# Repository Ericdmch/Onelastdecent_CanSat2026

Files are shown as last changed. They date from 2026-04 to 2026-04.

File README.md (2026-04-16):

# CanSat 2026

A student CanSat project for the 2026 competition. The system consists of a CanSat satellite unit that collects and transmits environmental and navigation telemetry, a ground station receiver that captures the radio packets, and a Python dashboard for real-time display and data logging.

---

## Repository Structure

```
Onelastdecent_CanSat2026/
├── Hardware/
│   ├── CanSat 2026.step          # CanSat mechanical design
│   └── Ground Station.step       # Ground station enclosure design
└── Software/
    ├── CanSat_Main_Transmitter/  # CanSat onboard firmware (Pico 2 W)
    └── CanSat_Main_Reciever/     # Ground station firmware (Pico 2) + dashboard
        └── dashboard/            # Python ground station dashboard
```

---

## System Overview

### CanSat (Transmitter)

**Hardware**
| Component | Part | Interface |
|---|---|---|
| Microcontroller | Raspberry Pi Pico 2 W (RP2350) | — |
| Environmental sensor | BME680 | I2C0 — SDA GP4, SCL GP5 |
| Radio | E220-900T30D (LoRa 915 MHz, 30 dBm) | UART0 — TX GP0, RX GP1, M0 GP2, M1 GP3, AUX GP6 |
| Flight controller | MicoAir743V2 (ArduPilot) — GPS + IMU | UART1 — TX GP8, RX GP9 |
| Status LED | WS2812B NeoPixel | PIO — GP7 |

The CanSat firmware runs at 1 Hz. Each loop it reads the BME680, polls the flight controller for GPS position and attitude over MAVLink, builds a CSV telemetry packet, and transmits it via the E220 radio. Sensor values are also logged to the flight controller's DataFlash via `NAMED_VALUE_FLOAT` MAVLink messages.

**NeoPixel status codes**

| Colour | Meaning |
|---|---|
| Green | All sensors valid, radio OK |
| Yellow | BME680 invalid, radio OK |
| Orange | Radio transmit timeout |
| Red | BME680 not found at boot |

---

### Ground Station (Receiver)

**Hardware**
| Component | Part | Interface |
|---|---|---|
| Microcontroller | Raspberry Pi Pico 2 (RP2350) | — |
| Radio | E220-900T30D (LoRa 915 MHz, 30 dBm) | UART0 — TX GP0, RX GP1, M0 GP2, M1 GP3, AUX GP6 |
| GPS | HGLRC M100-5883 | UART1 — TX GP4, RX GP5 |
| Status LED | WS2812B NeoPixel | PIO — GP7 |
| Onboard LED | GP25 | GPIO |

The receiver firmware forwards received `$CANSAT` packets verbatim to USB serial. It also parses NMEA GGA sentences from the ground station GPS and emits `$GSPOS` lines to USB so the dashboard can display the ground station's own position and calculate distance/bearing to the CanSat.

**NeoPixel status codes**

| Colour | Meaning |
|---|---|
| Green flash | Packet received |
| Red flash | No packet in the last 2 s |
| Solid orange | E220 configuration in progress |

---

## Telemetry Packet Format

All packets are newline-terminated ASCII sent over USB serial at any baud rate.

**CanSat telemetry**
```
$CANSAT,<ms>,<temp>,<press>,<hum>,<gas>,<lat_e7>,<lon_e7>,<alt_mm>,<roll>,<pitch>,<yaw>,<fc_bytes>,<stx_v1>,<stx_v2>
```

| Field | Unit | Notes |
|---|---|---|
| `ms` | ms | Time since boot |
| `temp` | °C | BME680 temperature (PCB offset applied) |
| `press` | hPa | Barometric pressure |
| `hum` | % | Relative humidity |
| `gas` | Ω | Gas resistance |
| `lat_e7` / `lon_e7` | deg × 10⁷ | GPS position from ArduPilot FC |
| `alt_mm` | mm | GPS altitude |
| `roll` / `pitch` / `yaw` | deg | Attitude from ArduPilot FC |
| `fc_bytes` / `stx_v1` / `stx_v2` | — | FC UART debug counters |

**Ground station GPS**
```
$GSPOS,<lat_e7>,<lon_e7>,<alt_mm>,<hdop_100>,<fix>
```

**Radio frequency broadcast** (sent by CanSat every ~10 s)
```
$FREQ,<freq_mhz>,<channel>
```

---

## Radio Configuration

Both E220 modules are configured at boot to:

| Parameter | Value |
|---|---|
| Frequency | 915.125 MHz (channel 65) |
| Air data rate | 2.4 kbps |
| UART baud | 9600 |
| TX power | 30 dBm |
| Sub-packet size | 200 B |
| Mode | Transparent |

---

## Ground Station Dashboard

A Python/Tkinter application providing real-time telemetry display, live graphs, a GPS map view, and CSV data recording.

### Setup

```bash
cd Software/CanSat_Main_Reciever/dashboard
pip install -r requirements.txt
python3 ground_station.py
```

**Dependencies:** `pyserial`, `matplotlib`, `tkintermapview` (optional — required for tile map view)

### Features

- Connect to any serial port at 9600 or 115200 baud
- Live telemetry panel: environmental, navigation, and attitude data
- Six real-time graphs: temperature, pressure, humidity, altitude, orientation, gas resistance
- GPS map tab with tile map (online) and simple offline scatter plot
- Ground station GPS overlay showing position, distance, and bearing to CanSat
- Radio frequency badge updated automatically from `$FREQ` packets
- CSV recording and export
- Signal loss overlay when no packets are received for > 5 s

---

## Firmware Build Instructions

Both firmware projects use the [Raspberry Pi Pico SDK](https://github.com/raspberrypi/pico-sdk) and are configured for VS Code with the Pico extension.

**Prerequisites:** CMake ≥ 3.13, ARM GCC toolchain, Pico SDK 2.2.0

```bash
cd Software/CanSat_Main_Transmitter   # or CanSat_Main_Reciever
mkdir build && cd build
cmake ..
make -j4
```

Flash the resulting `.uf2` file by holding BOOTSEL on the Pico while connecting via USB, then copying the file to the mounted drive.

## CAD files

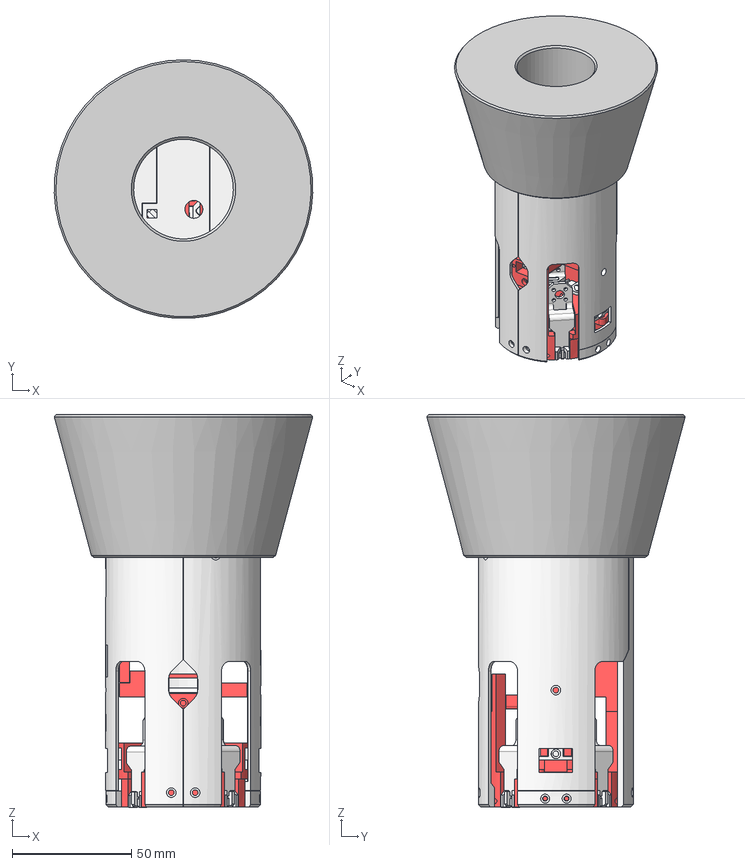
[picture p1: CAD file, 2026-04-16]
Hardware/CanSat 2026.step
108.3 x 108.3 x 164.6 mm

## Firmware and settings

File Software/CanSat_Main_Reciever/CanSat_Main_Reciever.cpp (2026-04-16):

//
// CanSat 2026 — Ground Station Receiver Firmware
// Controller : Raspberry Pi Pico 2 (RP2350 Cortex-M33)
// Radio      : E220-900T30D via UART0 (TX=GP0, RX=GP1, M0=GP2, M1=GP3, AUX=GP6)
// Output     : USB serial — open at any baud rate in a serial monitor
//
// Received packets are forwarded verbatim to USB:
//   $CANSAT,<ms>,<temp>,<press>,<hum>,<gas>,<lat_e7>,<lon_e7>,<alt_mm>,<roll>,<pitch>,<yaw>
//

#include "pico/stdlib.h"
#include "hardware/uart.h"
#include "hardware/gpio.h"
#include "hardware/watchdog.h"
#include "hardware/pio.h"
#include "hardware/clocks.h"
#include "ws2812.pio.h"
#include <cstdint>
#include <cstdio>
#include <cstdlib>
#include <cstring>

static constexpr uint LED_PIN  = 25;

// ── NeoPixel (WS2812) ─────────────────────────────────────────────────────
static constexpr uint NEO_PIN  = 7;
static PIO  neo_pio = pio0;
static uint neo_sm  = 0;

static void neo_init() {
    uint offset = pio_add_program(neo_pio, &ws2812_program);
    ws2812_program_init(neo_pio, neo_sm, offset, NEO_PIN, 800000.f);
}

// Send 24-bit GRB color (WS2812 expects G-R-B order in the upper 24 bits)
static void neo_set(uint8_t r, uint8_t g, uint8_t b) {
    uint32_t grb = ((uint32_t)g << 24) | ((uint32_t)r << 16) | ((uint32_t)b << 8);
    pio_sm_put_blocking(neo_pio, neo_sm, grb);
}

// Brief color flash then off
static void neo_flash(uint8_t r, uint8_t g, uint8_t b, uint32_t ms) {
    neo_set(r, g, b);
    sleep_ms(ms);
    neo_set(0, 0, 0);
}

// ── E220 pin assignments ───────────────────────────────────────────────────
#define E220_UART      uart0
static constexpr uint E220_TX_PIN  = 0;
static constexpr uint E220_RX_PIN  = 1;
static constexpr uint E220_M0_PIN  = 2;
static constexpr uint E220_M1_PIN  = 3;
static constexpr uint E220_AUX_PIN = 6;
static constexpr uint E220_BAUD    = 9600;

// ── Watchdog ───────────────────────────────────────────────────────────────
static constexpr uint32_t WATCHDOG_MS = 8000;

// ── Packet buffer ─────────────────────────────────────────────────────────
static constexpr size_t BUF_SIZE = 256;

// ── Ground-Station GPS (UART1, HGLRC M100-5883) ───────────────────────────
// Wiring: GP4 → GPS RX (optional, config only),  GP5 ← GPS TX (NMEA out)
#define GPS_UART     uart1
static constexpr uint GPS_TX_PIN = 4;
static constexpr uint GPS_RX_PIN = 5;
static constexpr uint GPS_BAUD   = 9600;
static constexpr size_t GPS_LINE_SIZE = 128;

static struct {
    int32_t  lat_e7;
    int32_t  lon_e7;
    int32_t  alt_mm;
    uint16_t hdop_100;
    uint8_t  fix;      // 0 = no fix
} gs_gps = {};

static void gps_init() {
    uart_init(GPS_UART, GPS_BAUD);
    gpio_set_function(GPS_TX_PIN, GPIO_FUNC_UART);
    gpio_set_function(GPS_RX_PIN, GPIO_FUNC_UART);
    uart_set_format(GPS_UART, 8, 1, UART_PARITY_NONE);
    uart_set_fifo_enabled(GPS_UART, true);
    printf("[GPS] UART1 init: TX=GP%d RX=GP%d @%d baud\n",
           GPS_TX_PIN, GPS_RX_PIN, GPS_BAUD);
}

// Convert NMEA "DDMM.MMMMM" + hemisphere to integer degrees * 1e7
static int32_t nmea_to_e7(const char* s, char hemi) {
    if (!s || s[0] == '\0') return 0;
    int dot = 0;
    while (s[dot] && s[dot] != '.') dot++;
    if (dot < 2) return 0;
    int deg_chars = dot - 2;
    int32_t deg = 0;
    for (int i = 0; i < deg_chars; i++) {
        if (s[i] < '0' || s[i] > '9') return 0;
        deg = deg * 10 + (s[i] - '0');
    }
    double min = atof(s + deg_chars);
    double dd  = (double)deg + min / 60.0;
    if (hemi == 'S' || hemi == 'W') dd = -dd;
    return (int32_t)(dd * 1e7 + (dd >= 0.0 ? 0.5 : -0.5));
}

// Split a NMEA sentence in-place on ',' and '*'. Returns field count.
static int nmea_split(char* s, char* f[], int max) {
    int n = 0;
    f[n++] = s;
    while (*s && n < max) {
        if (*s == ',' || *s == '*') { *s = '\0'; f[n++] = s + 1; }
        s++;
    }
    return n;
}

// Parse any $GxGGA sentence and emit $GSPOS on USB
static void gps_parse_line(char* line) {
    // Accept $GPGGA, $GNGGA, $GLGGA, etc.
    if (line[0] != '$' || line[1] != 'G' ||
        line[3] != 'G' || line[4] != 'G' || line[5] != 'A' || line[6] != ',')
        return;

    char* f[20];
    int n = nmea_split(line, f, 20);
    if (n < 10) return;

    // f indices: 0=id 1=time 2=lat 3=N/S 4=lon 5=E/W 6=fix 7=sats 8=hdop 9=alt
    int fix = atoi(f[6]);
    if (fix == 0) { gs_gps.fix = 0; return; }

    gs_gps.lat_e7   = nmea_to_e7(f[2], f[3][0]);
    gs_gps.lon_e7   = nmea_to_e7(f[4], f[5][0]);
    gs_gps.alt_mm   = (int32_t)(atof(f[9]) * 1000.0 + 0.5);
    gs_gps.hdop_100 = (uint16_t)(atof(f[8]) * 100.0 + 0.5);
    gs_gps.fix      = (uint8_t)fix;

    printf("$GSPOS,%ld,%ld,%ld,%u,%u\n",
           (long)gs_gps.lat_e7, (long)gs_gps.lon_e7,
           (long)gs_gps.alt_mm, gs_gps.hdop_100, gs_gps.fix);
}

static char gps_buf[GPS_LINE_SIZE];
static int  gps_pos = 0;

static void gps_handle_char(char c) {
    if (c == '\n') {
        gps_buf[gps_pos] = '\0';
        if (gps_pos > 0 && gps_buf[0] == '$')
            gps_parse_line(gps_buf);
        gps_pos = 0;
    } else if (c != '\r') {
        if (gps_pos < (int)sizeof(gps_buf) - 1)
            gps_buf[gps_pos++] = c;
        else
            gps_pos = 0;  // overflow — discard
    }
}

// ── E220 helpers ──────────────────────────────────────────────────────────

static void e220_flush_rx_verbose() {
    while (uart_is_readable(E220_UART)) {
        uint8_t c = uart_getc(E220_UART);
        printf("  (flushed byte: 0x%02X)\n", c);
    }
}

static void e220_flush_rx() {
    int n = 0;
    while (uart_is_readable(E220_UART)) { uart_getc(E220_UART); n++; }
    if (n) printf("  (flushed %d bytes)\n", n);
}

static int e220_read_resp(uint8_t* buf, int max_len, uint32_t first_byte_us) {
    int len = 0;
    uint32_t timeout = first_byte_us;
    while (len < max_len && uart_is_readable_within_us(E220_UART, timeout)) {
        buf[len++] = uart_getc(E220_UART);
        timeout = 10000; // subsequent bytes: 10ms
    }
    return len;
}

static void e220_print_hex(const char* label, const uint8_t* buf, int len) {
    printf("%s", label);
    for (int i = 0; i < len; i++) printf("%02X ", buf[i]);
    printf("(%d bytes)\n", len);
}

// ── Probe: try BOTH binary and AT protocol ──────────────────────────────

enum ProbeResult { PROBE_NONE, PROBE_BINARY, PROBE_AT };

static ProbeResult e220_probe() {
    uint8_t resp[20];
    int rlen;

    // --- Try binary: C1 00 08 (reference library format) ---
    e220_flush_rx();
    const uint8_t bin_cmd[] = {0xC1, 0x00, 0x08};
    uart_write_blocking(E220_UART, bin_cmd, 3);
    sleep_ms(100);
    rlen = e220_read_resp(resp, sizeof(resp), 100000);
    if (rlen > 0) {
        e220_print_hex("  bin rx: ", resp, rlen);
        if (rlen >= 3 && resp[0] == 0xC1) return PROBE_BINARY;
    }

    // --- Try AT text: AT+ADDR?\r\n ---
    e220_flush_rx();
    const char* at_cmd = "AT+ADDR?\r\n";
    uart_write_blocking(E220_UART, (const uint8_t*)at_cmd, strlen(at_cmd));
    sleep_ms(200);
    rlen = e220_read_resp(resp, sizeof(resp), 100000);
    if (rlen > 0) {
        resp[rlen < 19 ? rlen : 19] = '\0';
        printf("  at rx: \"%s\" (%d bytes)\n", (char*)resp, rlen);
        if (strstr((char*)resp, "OK") || strstr((char*)resp, "AT") || rlen >= 2)
            return PROBE_AT;
    }

    return PROBE_NONE;
}

// ── Config write (binary protocol) ──────────────────────────────────────

static bool e220_write_config_binary() {
    // C0 = permanent save (per reference library; C2 = temporary)
    const uint8_t config[] = {
        0xC0,   // permanent write
        0x00,   // start register
        0x08,   // 8 registers (no NETID in this variant)
        0x00,   // ADDH  = 0
        0x00,   // ADDL  = 0
        0x62,   // SPED: UART 9600, 8N1, air 2.4 kbps
        0x00,   // OPTION: sub-pkt 200B, RSSI off, 30 dBm
        0x41,   // CHAN: channel 65 → 915.125 MHz
        0x00,   // TRANS_MODE: transparent, no relay/LBT/WOR
        0x00,   // CRYPT_H
        0x00,   // CRYPT_L
    };

    e220_flush_rx();
    uart_write_blocking(E220_UART, config, sizeof(config));
    sleep_ms(200);

    uint8_t resp[16];
    int rlen = e220_read_resp(resp, sizeof(resp), 100000);
    if (rlen >= 3 && resp[0] == 0xC1) {
        e220_print_hex("[E220] Write OK (bin): ", resp, rlen);
        return true;
    }
    if (rlen > 0) e220_print_hex("[E220] Write resp: ", resp, rlen);
    return false;
}

// ── Config write (AT protocol) ──────────────────────────────────────────

static bool e220_at_cmd(const char* cmd) {
    e220_flush_rx();
    uart_write_blocking(E220_UART, (const uint8_t*)cmd, strlen(cmd));
    sleep_ms(200);

    char resp[32];
    int rlen = 0;
    while (rlen < (int)sizeof(resp) - 1 && uart_is_readable_within_us(E220_UART, 50000)) {
        uint8_t c = uart_getc(E220_UART);
        if (c >= 0x20 && c < 0x7f) resp[rlen++] = (char)c;
    }
    resp[rlen] = '\0';

    if (rlen > 0) printf("  [%s] -> \"%s\"\n", cmd, resp);
    return strstr(resp, "OK") != nullptr;
}

static void e220_write_config_at() {
    const char* cmds[] = {
        "AT+ADDR=0\r\n",
        "AT+CHANNEL=65\r\n",
        "AT+RATE=2\r\n",
        "AT+TRANS=0\r\n",
        "AT+POWER=0\r\n",
        "AT+UART=3,0\r\n",
        "AT+PACKET=0\r\n",
    };
    for (int i = 0; i < 7; i++) {
        if (!e220_at_cmd(cmds[i]))
            printf("  WARN: %s no OK\n", cmds[i]);
    }
}

// ── E220 configure ──────────────────────────────────────────────────────

static void e220_configure() {
    // --- GPIO: start with M0=HIGH, M1=HIGH (config mode from boot) ---
    gpio_init(E220_M0_PIN);  gpio_set_dir(E220_M0_PIN, GPIO_OUT);  gpio_put(E220_M0_PIN, 1);
    gpio_init(E220_M1_PIN);  gpio_set_dir(E220_M1_PIN, GPIO_OUT);  gpio_put(E220_M1_PIN, 1);
    gpio_init(E220_AUX_PIN); gpio_set_dir(E220_AUX_PIN, GPIO_IN);
    gpio_pull_up(E220_AUX_PIN);

    // --- UART ---
    uint actual_baud = uart_init(E220_UART, E220_BAUD);
    gpio_set_function(E220_TX_PIN, GPIO_FUNC_UART);
    gpio_set_function(E220_RX_PIN, GPIO_FUNC_UART);
    uart_set_format(E220_UART, 8, 1, UART_PARITY_NONE);
    uart_set_fifo_enabled(E220_UART, true);

    printf("[E220] UART baud=%u actual=%u\n", E220_BAUD, actual_baud);
    printf("[E220] Pins: TX=GP%d RX=GP%d M0=GP%d M1=GP%d AUX=GP%d\n",
           E220_TX_PIN, E220_RX_PIN, E220_M0_PIN, E220_M1_PIN, E220_AUX_PIN);

    // --- Line-level check ---
    gpio_set_function(E220_RX_PIN, GPIO_FUNC_SIO);
    gpio_set_dir(E220_RX_PIN, GPIO_IN);
    gpio_disable_pulls(E220_RX_PIN);
    sleep_ms(5);
    bool rx_level = gpio_get(E220_RX_PIN);
    printf("[E220] GP1 (RX) no-pull=%d %s\n", rx_level,
           rx_level ? "(E220 TXD connected)" : "*** NOT CONNECTED ***");
    gpio_set_function(E220_RX_PIN, GPIO_FUNC_UART);

    // --- Wait for AUX HIGH ---
    printf("[E220] Waiting for AUX HIGH (config mode)...\n");
    for (int i = 0; i < 300; i++) {
        if (gpio_get(E220_AUX_PIN)) break;
        if (i % 50 == 0) printf("  AUX=%d @%dms\n", gpio_get(E220_AUX_PIN), i * 10);
        sleep_ms(10);
    }
    sleep_ms(200);

    // Print the stale byte if there is one
    e220_flush_rx_verbose();

    printf("[E220] M0=%d M1=%d AUX=%d — probing...\n",
           gpio_get(E220_M0_PIN), gpio_get(E220_M1_PIN), gpio_get(E220_AUX_PIN));

    // --- Probe at multiple baud rates and all M0/M1 mode combos ---
    const uint32_t bauds[] = {9600, 115200, 57600, 19200, 38400, 4800, 2400, 1200};
    const int num_bauds = sizeof(bauds) / sizeof(bauds[0]);

    ProbeResult result = PROBE_NONE;

    // First: try 9600 with M0=1 M1=1 (standard config mode), 5 quick probes
    printf("[E220] === 9600 baud, M0=1 M1=1 (5 probes) ===\n");
    for (int i = 0; i < 5 && result == PROBE_NONE; i++) {
        printf("  [probe %d] ", i + 1);
        result = e220_probe();
        if (result == PROBE_NONE) { printf("  no response\n"); sleep_ms(300); }
    }

    // Second: try all other baud rates with M0=1 M1=1
    if (result == PROBE_NONE) {
        for (int b = 1; b < num_bauds && result == PROBE_NONE; b++) {
            uart_set_baudrate(E220_UART, bauds[b]);
            printf("[E220] === %lu baud, M0=1 M1=1 ===\n", (unsigned long)bauds[b]);
            e220_flush_rx_verbose();
            for (int i = 0; i < 3 && result == PROBE_NONE; i++) {
                printf("  [probe %d] ", i + 1);
                result = e220_probe();
                if (result == PROBE_NONE) { printf("  no response\n"); sleep_ms(200); }
            }
        }
        // Restore 9600
        uart_set_baudrate(E220_UART, 9600);
    }

    // Third: try other M0/M1 combos at 9600
    if (result == PROBE_NONE) {
        // M0=0 M1=1
        printf("[E220] === 9600 baud, M0=0 M1=1 ===\n");
        gpio_put(E220_M0_PIN, 0); gpio_put(E220_M1_PIN, 1);
        sleep_ms(500);
        for (int i = 0; i < 3 && result == PROBE_NONE; i++) {
            printf("  [probe %d] ", i + 1);
            result = e220_probe();
            if (result == PROBE_NONE) { printf("  no response\n"); sleep_ms(200); }
        }

        // M0=1 M1=0
        printf("[E220] === 9600 baud, M0=1 M1=0 ===\n");
        gpio_put(E220_M0_PIN, 1); gpio_put(E220_M1_PIN, 0);
        sleep_ms(500);
        for (int i = 0; i < 3 && result == PROBE_NONE; i++) {
            printf("  [probe %d] ", i + 1);
            result = e220_probe();
            if (result == PROBE_NONE) { printf("  no response\n"); sleep_ms(200); }
        }

        // Restore config mode
        gpio_put(E220_M0_PIN, 1); gpio_put(E220_M1_PIN, 1);
        sleep_ms(500);
    }

    if (result == PROBE_NONE) {
        printf("\n[E220] Exhausted all baud rates and mode combos. No response.\n");
        printf("  The module is connected (TXD drives GP1 HIGH, AUX HIGH)\n");
        printf("  but does not respond to any command.\n");
        printf("[E220] Continuing without config — using factory defaults.\n");
    }

    // --- Write configuration using whichever protocol worked ---
    if (result == PROBE_BINARY) {
        printf("[E220] Using binary protocol\n");
        if (!e220_write_config_binary())
            printf("[E220] WARN: binary write failed\n");
    } else if (result == PROBE_AT) {
        printf("[E220] Using AT protocol\n");
        e220_write_config_at();
    }
    // result == PROBE_NONE: skip config, use factory defaults

    // --- Return to normal mode ---
    gpio_put(E220_M0_PIN, 0);
    gpio_put(E220_M1_PIN, 0);
    sleep_ms(500);
    for (int i = 0; i < 100; i++) {
        if (gpio_get(E220_AUX_PIN)) break;
        sleep_ms(10);
    }
    printf("[E220] Normal mode. AUX=%d — Ready\n", gpio_get(E220_AUX_PIN));
}

int main() {
    stdio_init_all();
    sleep_ms(3000);  // wait for serial monitor to connect

    gpio_init(LED_PIN);
    gpio_set_dir(LED_PIN, GPIO_OUT);
    neo_init();

    if (watchdog_caused_reboot()) {
        printf("[BOOT] Watchdog reboot\n");
    }

    // Configure E220 — solid orange while busy
    neo_set(255, 80, 0);
    e220_configure();
    neo_set(0, 0, 0);

    // Ground-station GPS
    gps_init();

    watchdog_enable(WATCHDOG_MS, true);
    printf("[OK] Ground station ready — waiting for packets\n");
    gpio_put(LED_PIN, 1); // LED solid = ready

    // ── Receive loop ──────────────────────────────────────────────────────
    char line[BUF_SIZE];
    int  pos = 0;
    uint32_t last_heartbeat_ms = 0;
    uint32_t last_packet_ms    = 0;

    while (true) {
        watchdog_update();

        uint32_t now = to_ms_since_boot(get_absolute_time());
        if (now - last_heartbeat_ms >= 500) {
            printf("[SCAN] Listening for CanSat...\n");
            last_heartbeat_ms = now;
            // Flash red when no packet received in the last 2 s
            if (now - last_packet_ms >= 2000) {
                neo_flash(255, 0, 0, 200);
            }
        }

        // Poll ground-station GPS (UART1)
        while (uart_is_readable(GPS_UART))
            gps_handle_char((char)uart_getc(GPS_UART));

        if (!uart_is_readable(E220_UART)) {
            sleep_us(200);
            continue;
        }

        char c = uart_getc(E220_UART);

        if (c == '\n') {
            line[pos] = '\0';
            if (pos > 0 && line[0] == '$') {
                // Forward complete packet to USB
                printf("%s\n", line);
                last_packet_ms = now;
                // Green flash = packet received; brief LED blink as backup indicator
                neo_flash(0, 255, 0, 15);
                gpio_put(LED_PIN, 0);
                sleep_ms(30);
                gpio_put(LED_PIN, 1);
            }
            pos = 0;
        } else if (c != '\r') {
            if (pos < (int)sizeof(line) - 1) {
                line[pos++] = c;
            } else {
                pos = 0; // line overflow — discard and reset
            }
        }
    }
}

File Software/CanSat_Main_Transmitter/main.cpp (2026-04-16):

//
// CanSat 2026 — Primary Mission Firmware
// Controller : Raspberry Pi Pico 2 W (RP2350 Cortex-M33)
// Sensor     : BME680  via I2C0  (SDA=GP4, SCL=GP5)
// Radio      : E220-900T30D via UART0 (TX=GP0, RX=GP1, M0=GP2, M1=GP3, AUX=GP6)
// FC Link    : MicoAir743V2 (ArduPilot) via UART1 (TX=GP8, RX=GP9)
// NeoPixel   : WS2812B via PIO (DIN=GP7)
//

#include "pico/stdlib.h"
#include "pico/cyw43_arch.h"
#include "hardware/i2c.h"
#include "hardware/watchdog.h"
#include "hardware/clocks.h"

#include "bme680.hpp"
#include "e220.hpp"
#include "fc_link.hpp"
#include "neopixel.hpp"

#include <cstdio>
#include <cstring>

// ── Pin assignments ────────────────────────────────────────────────────────
static constexpr uint I2C0_SDA = 4;
static constexpr uint I2C0_SCL = 5;

// ── Calibration ────────────────────────────────────────────────────────────
static constexpr float TEMP_OFFSET_C = -6.51f; // corrects for PCB self-heating

// ── Radio frequency ────────────────────────────────────────────────────────
static constexpr uint E220_CHANNEL  = 65;
static constexpr float   E220_FREQ_MHZ = 850.125f + E220_CHANNEL; // 915.125 MHz

// ── Timing ─────────────────────────────────────────────────────────────────
static constexpr uint32_t LOOP_PERIOD_MS  = 1000; // 1 Hz telemetry
static constexpr uint32_t WATCHDOG_MS     = 2000; // reboot if loop hangs

// ── Globals ────────────────────────────────────────────────────────────────
static BME680  bme(i2c0);
static E220    radio;
static FCLink  fc;

// ── Helpers ────────────────────────────────────────────────────────────────
static void led_blink(uint n) {
    for (uint i = 0; i < n; i++) {
        cyw43_arch_gpio_put(CYW43_WL_GPIO_LED_PIN, 1); sleep_ms(80);
        cyw43_arch_gpio_put(CYW43_WL_GPIO_LED_PIN, 0); sleep_ms(80);
    }
}

// Build CSV telemetry packet into buf; returns number of chars written
// Format: $CANSAT,<ms>,<temp>,<press>,<hum>,<gas>,<lat_e7>,<lon_e7>,<alt_mm>,<roll_deg>,<pitch_deg>,<yaw_deg>\r\n
static int build_packet(char* buf, size_t bufsz,
                        uint32_t timestamp_ms,
                        const BME680Data& env,
                        const FCData& fc_d,
                        uint32_t fc_bytes,
                        uint32_t stx_v1,
                        uint32_t stx_v2)
{
    const float R2D = 57.2957795f;

    int n = snprintf(buf, bufsz,
        "$CANSAT,%lu,"
        "%.2f,%.2f,%.2f,%.0f,"
        "%ld,%ld,%ld,"
        "%.1f,%.1f,%.1f,"
        "%lu,%lu,%lu"
        "\r\n",
        (unsigned long)timestamp_ms,
        // BME680
        env.valid ? env.temperature + TEMP_OFFSET_C : -999.0f,
        env.valid ? env.pressure      : -999.0f,
        env.valid ? env.humidity      : -999.0f,
        env.valid ? env.gas_resistance: -999.0f,
        // GPS
        fc_d.gps_valid ? (long)fc_d.lat    : 0L,
        fc_d.gps_valid ? (long)fc_d.lon    : 0L,
        fc_d.gps_valid ? (long)fc_d.alt_mm : 0L,
        // Attitude (convert rad→deg)
        fc_d.att_valid ? fc_d.roll  * R2D : 0.0f,
        fc_d.att_valid ? fc_d.pitch * R2D : 0.0f,
        fc_d.att_valid ? fc_d.yaw   * R2D : 0.0f,
        // Raw FC UART byte counter and MAVLink version probe (debug)
        (unsigned long)fc_bytes,
        (unsigned long)stx_v1,
        (unsigned long)stx_v2
    );
    return n;
}

// ── Entry point ────────────────────────────────────────────────────────────
int main() {
    // --- USB stdio for debug output (UART0 reserved for E220)
    stdio_init_all();
    sleep_ms(2000); // allow time to open serial monitor before config output begins

    // --- CYW43 (required for onboard LED on Pico W)
    cyw43_arch_init();

    // --- NeoPixel
    neopixel_init();

    if (watchdog_caused_reboot()) {
        printf("[BOOT] Watchdog reboot detected\n");
    }

    // --- I2C0 for BME680 (400 kHz)
    i2c_init(i2c0, 400 * 1000);
    gpio_set_function(I2C0_SDA, GPIO_FUNC_I2C);
    gpio_set_function(I2C0_SCL, GPIO_FUNC_I2C);
    gpio_pull_up(I2C0_SDA);
    gpio_pull_up(I2C0_SCL);

    // --- Peripherals
    radio.init();

    printf("[E220] TX frequency: %.3f MHz (channel %u)\n", (double)E220_FREQ_MHZ, E220_CHANNEL);
    {
        char freq_msg[48];
        int n = snprintf(freq_msg, sizeof(freq_msg), "$FREQ,%.3f,CH%u\r\n", (double)E220_FREQ_MHZ, E220_CHANNEL);
        radio.transmit(reinterpret_cast<uint8_t*>(freq_msg), (size_t)n);
    }

    fc.init();

    // --- BME680
    bool bme_ok = bme.init();
    if (!bme_ok) {
        printf("[WARN] BME680 not found — continuing without sensor\n");
        neopixel_set(100, 0, 0); // red = sensor error
        led_blink(5);
    } else {
        printf("[OK] BME680 initialised\n");
        neopixel_set(0, 100, 0); // green = all good
        led_blink(2);
    }

    printf("[OK] System ready. Starting 1Hz loop.\n");

    // --- Watchdog: enable after all init — radio.init() alone can take >2s
    watchdog_enable(WATCHDOG_MS, true /*pause on debug*/);

    // ── Main loop (1 Hz) ───────────────────────────────────────────────────
    uint32_t loop_count = 0;
    while (true) {
        absolute_time_t loop_start = get_absolute_time();
        watchdog_update();
        ++loop_count;

        // 1. Toggle LED to show life
        cyw43_arch_gpio_put(CYW43_WL_GPIO_LED_PIN, 1);

        // 2. Drain FC UART; fc.update() is non-blocking
        for (int i = 0; i < 100; i++) fc.update();

        // 3. Read BME680 (blocks ~200ms in forced mode)
        BME680Data env{};
        if (bme_ok) {
            if (!bme.read(env)) {
                printf("[WARN] BME680 read failed\n");
            }
        }

        watchdog_update(); // pet after the blocking sensor read

        // 4. Build telemetry string
        char packet[160];
        uint32_t ts = to_ms_since_boot(get_absolute_time());
        int plen = build_packet(packet, sizeof(packet), ts, env, fc.data(), fc.bytes_received(), fc.stx_v1_count(), fc.stx_v2_count());

        // 6. Print to USB (debug)
        printf("%s", packet);

        // 6a. Log BME680 values to FC DataFlash via MAVLink NAMED_VALUE_FLOAT
        if (env.valid) {
            fc.send_named_float(ts, "TEMP",  env.temperature + TEMP_OFFSET_C);
            fc.send_named_float(ts, "PRESS", env.pressure);
            fc.send_named_float(ts, "HUMID", env.humidity);
            fc.send_named_float(ts, "GAS",   env.gas_resistance);
        }

        // 7. Re-broadcast frequency packet every 10 loops so the ground station
        //    can pick it up even if it connects after boot
        if (loop_count % 10 == 1) {
            char freq_msg[48];
            int fn = snprintf(freq_msg, sizeof(freq_msg),
                              "$FREQ,%.3f,CH%u\r\n",
                              (double)E220_FREQ_MHZ, E220_CHANNEL);
            radio.transmit(reinterpret_cast<uint8_t*>(freq_msg), (size_t)fn);
            watchdog_update();
        }
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

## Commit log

2026-03-26 fixed radio initialization (still need to work on reciever)
    [CanSat_Main_Reciever.cpp, e220.cpp, main.cpp]
2026-04-16 final commit
    [CanSat 2026.step]
